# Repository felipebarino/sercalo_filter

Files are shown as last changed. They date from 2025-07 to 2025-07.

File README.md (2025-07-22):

Excelente\! Fico feliz em saber que a correção funcionou bem. O código está muito mais robusto agora.

Com base na sua versão `1.0.0` do `main.c`, reescrevi o `README.md` para refletir com precisão todas as funcionalidades e comandos atuais. Ele está mais claro e agora inclui os comandos de energia que você adicionou.

Aqui está a versão atualizada:

-----

# Controle do Filtro Óptico Sintonizável Sercalo TF1 via ESP32

Este projeto implementa um firmware para o microcontrolador ESP32 para controlar um Filtro Óptico Sintonizável Sercalo TF1. A comunicação com os filtros (Banda C e Banda L) é feita via I2C.

A aplicação principal de exemplo estabelece uma interface de controle via porta serial (UART), permitindo que um usuário ou um programa envie comandos para consultar o estado dos filtros, definir comprimentos de onda específicos ou iniciar varreduras de espectro contínuas.

## Funcionalidades

  * **Driver I2C Dedicado:** Um componente (`sercalo_i2c_driver`) encapsula a comunicação e os comandos do protocolo I2C do filtro Sercalo TF1, de acordo com o manual do fabricante, incluindo cálculo de CRC-8 para garantir a integridade dos dados.
  * **Arquitetura Baseada em FreeRTOS:** A aplicação utiliza o FreeRTOS para gerenciar tarefas de comunicação e controle, permitindo uma operação não bloqueante e facilmente expansível.
  * **Sistema de Comandos Escalável:** A lógica de processamento de comandos utiliza uma tabela de despacho (*dispatch table*), tornando a adição de novos comandos simples e organizada, sem a necessidade de alterar o fluxo principal.
  * **Controle Robusto via Serial:** Comandos para identificar os filtros, definir comprimentos de onda, obter o estado atual e iniciar varreduras foram implementados. O protocolo é similar ao SCPI, facilitando a automação.
  * **Gerenciamento Automático de Energia:** O firmware garante que os filtros sejam ativados (retirados do modo de repouso) automaticamente antes de executar comandos de operação, aumentando a confiabilidade do sistema.

## Hardware Necessário

  * Placa de desenvolvimento ESP32.
  * Filtro Óptico Sintonizável Sercalo TF1 (Banda C e/ou L).
  * Conexões I2C entre o ESP32 e os filtros (SDA, SCL).
      * No projeto, os pinos estão configurados como:
          * **SCL:** GPIO 22
          * **SDA:** GPIO 21
  * Fonte de alimentação para o ESP32 e para os filtros Sercalo.
  * Cabo USB para programação do ESP32 e para monitoramento/controle via terminal serial.

## Estrutura do Projeto

```text
sercalo_filter/
├── main/
│   ├── CMakeLists.txt
│   └── main.c                  # Lógica principal, tasks e handlers de comando
├── components/
│   └── sercalo_i2c_driver/
│       ├── CMakeLists.txt
│       ├── include/
│       │   └── sercalo_i2c.h   # Interface pública do driver
│       └── sercalo_i2c.c       # Implementação do driver I2C
├── CMakeLists.txt              # CMake principal do projeto
├── sdkconfig                   # Configuração do projeto ESP-IDF
└── README.md                   # Este arquivo
```

## Como Compilar e Gravar

1.  **Configure o Ambiente ESP-IDF:** Certifique-se de que o ESP-IDF está instalado e que as variáveis de ambiente foram exportadas (`. export.sh` ou `get_idf`).

2.  **Configure o Projeto:**

      * Defina o target do ESP32: `idf.py set-target esp32`.
      * Ajuste as configurações do projeto, se necessário, com `idf.py menuconfig`.
          * Verifique se as configurações de GPIO para I2C em `main/main.c` correspondem ao seu hardware.

3.  **Compile o Projeto:**

    ```bash
    idf.py build
    ```

4.  **Grave o Firmware no ESP32:**

      * Conecte o ESP32 ao computador.
      * Execute o comando abaixo, substituindo `/dev/ttyUSB0` pela porta serial correta.
        ```bash
        idf.py -p /dev/ttyUSB0 flash monitor
        ```
      * O comando `monitor` abrirá o terminal serial para interagir com o dispositivo.

## Protocolo de Comunicação

Todos os comandos são enviados via UART e devem seguir um formato específico.

1.  **Início do Comando:** Todo comando deve começar com o caractere dois-pontos (`:`).
2.  **Corpo do Comando:** Segue o nome do comando e seus argumentos, separados por `?` ou `:`.
3.  **Fim do Comando:** O comando é finalizado com um caractere de nova linha (`\n` ou `\r`).

**Formato Geral:**

```
:comando[?|:][argumentos]\n
```

### Formato das Respostas

  * **Sucesso:** A resposta começa com `:ACK`, opcionalmente seguida por dados.
    ```
    :ACK
    :ACK:[dados da resposta]
    ```
  * **Erro:** A resposta começa com `:NACK`, seguida por uma mensagem que descreve o erro.
    ```
    :NACK:[mensagem de erro]
    ```

-----

## Referência de Comandos

### `iden`

Recupera as informações de identificação de ambos os filtros (Banda C e Banda L).

  * **Descrição:** Solicita modelo, número de série (S/N) e versão de firmware de cada canal.
  * **Sintaxe:**
    ```
    :iden\n
    ```
  * **Exemplo de Resposta:**
    ```
    :ACK: Canal C: Modelo=TF, S/N=N/A, FW=7.0 | Canal L: Modelo=TF, S/N=N/A, FW=6.0 | 
    ```

### `get-interval`

Obtém o intervalo operacional (comprimentos de onda mínimo e máximo) de um filtro específico.

  * **Sintaxe:**
    ```
    :get-interval?[banda]\n
    ```
  * **Argumentos:**
      * `banda`: O canal do filtro (`C` ou `L`).
  * **Exemplo de Uso:**
      * **Comando:** `:get-interval?C\n`
      * **Resposta:** `:ACK:(1527.608,1565.503)`

### `get-wl`

Obtém o comprimento de onda (`wavelength`) atual de um filtro específico.

  * **Sintaxe:**
    ```
    :get-wl?[banda]\n
    ```
  * **Argumentos:**
      * `banda`: O canal do filtro (`C` ou `L`).
  * **Exemplo de Uso:**
      * **Comando:** `:get-wl?L\n`
      * **Resposta:** `:ACK:1575.500`

### `set-wl`

Define um novo comprimento de onda para um filtro específico.

  * **Descrição:** Sintoniza o canal para um novo comprimento de onda. Se uma varredura (`sweep`) estiver ativa, ela será interrompida.
  * **Sintaxe:**
    ```
    :set-wl:[banda]:[wavelength]\n
    ```
  * **Argumentos:**
      * `banda`: O canal do filtro a ser sintonizado (`C` ou `L`).
      * `wavelength`: O comprimento de onda desejado em nanômetros (nm).
  * **Exemplo de Uso:**
      * **Comando:** `:set-wl:C:1550.5\n`
      * **Resposta:** `:ACK`

### `sweep`

Inicia uma varredura contínua de comprimento de onda para um filtro. ⚙️

  * **Descrição:** Inicia uma tarefa que varre uma faixa de comprimentos de onda em intervalos de tempo definidos. A varredura reinicia automaticamente ao chegar ao fim. Se uma varredura já estiver ativa no canal, ela será substituída.
  * **Sintaxe:**
    ```
    :sweep:[banda]:[min_wl]:[max_wl]:[passo_wl]:[passo_tempo_ms]\n
    ```
  * **Argumentos:**
      * `banda`: O canal do filtro (`C` ou `L`).
      * `min_wl`: Comprimento de onda inicial (nm).
      * `max_wl`: Comprimento de onda final (nm).
      * `passo_wl`: Incremento do comprimento de onda a cada passo (nm).
      * `passo_tempo_ms`: Intervalo de tempo entre cada passo (milissegundos).
  * **Exemplo de Uso:**
      * **Comando:** `:sweep:L:1570:1605:0.5:1000\n`
      * **Resposta:** `:ACK`

### `powerup`

Força a ativação (modo de energia normal) de ambos os filtros.

  * **Descrição:** Garante que ambos os canais estejam prontos para receber comandos de operação.
  * **Sintaxe:**
    ```
    :powerup\n
    ```
  * **Exemplo de Resposta:**
    ```
    :ACK:Canal C: Ligado | Canal L: Ligado | 
    ```

### `get-power`

Verifica o estado de energia atual de ambos os filtros.

  * **Descrição:** Retorna `1` para modo normal (ligado) e `0` para modo de baixo consumo (repouso).
  * **Sintaxe:**
    ```
    :get-power\n
    ```
  * **Exemplo de Resposta:**
    ```
    :ACK:Canal C: 1 | Canal L: 1 | 
    ```

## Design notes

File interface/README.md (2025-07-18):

# Interface de controle do filtro sintonizável

Este programa é um exemplo para controle do filtro sintonizável via interface USB usando PyQt5 para construir a interface do usuário.

### Estrutura do Projeto (interface)

```
interface/
├── widgets/
│   ├── __init__.py
│   ├── base_widget.py      # Template para o widget de comando
│   ├── get_iden_widget.py  # Obter dados dos dispositivos
│   ├── get_wl_widget.py    # Obter comprimento de onda
│   ├── set_wl_widget.py    # Controle do comprimento de onda
│   └── sweep_widget.py     # Controle da varredura
├── main.py                 # Ponto de entrada
├── main_window.py          # Tela principal
├── communication.py        # Módulo de comunicações
└── README.md               # Este arquivo de documentação
```

## Referência de Comandos da UART

O dispositivo se comunica via UART usando o seguinte protocolo:

  - **Formato do Comando:** `:comando[?|:][argumentos]\n`
  - **Resposta de Sucesso:** `:ACK:[dados]\n` ou `:ACK\n`
  - **Resposta de Falha:** `:NACK:[mensagem_erro]\n`

| Comando | Descrição | Exemplo de Uso | Resposta de Sucesso Esperada |
| :--- | :--- | :--- | :--- |
| `iden?` | Obtém a identificação (Modelo, S/N, FW) de ambos os filtros. | `:iden?\n` | `:ACK: Canal C: ... \| Canal L: ... \|` |
| `get-interval?[B]`| Obtém o intervalo de WL (min, max) da banda `[B]` (`C` ou `L`). | `:get-interval?C\n` | `:ACK: (1527.608,1565.503)` |
| `get-wl?[B]` | Obtém o WL atual da banda `[B]`. | `:get-wl?L\n` | `:ACK: 1575.500` |
| `set-wl:[B]:[W]` | Define o WL `[W]` para a banda `[B]`. Para a varredura se ativa. | `:set-wl:C:1550.5\n` | `:ACK` |
| `sweep:[B]:[..]`| Inicia uma varredura. Args: `B:min:max:passo_wl:passo_t`. | `:sweep:L:1570:1605:0.5:1000\n` | `:ACK` |

## Requisitos

  - Python 3.7+
  - Bibliotecas: `PyQt5` e `pyserial`

## Instalação

1.  **Navegue até a pasta da interface:**
    ```bash
    cd sercalo_filter/interface
    ```
2.  **Instale as dependências:**
    ```bash
    pip install PyQt5 pyserial
    ```

## Como Usar

1.  **Execute a Aplicação:**
    ```bash
    python main.py
    ```
2.  **Conecte ao Dispositivo:**
      - Selecione a porta serial correta na lista suspensa (onde o seu ESP32 está conectado).
      - Clique em "Atualizar" se a porta não aparecer.
      - Clique em "Conectar". O botão mudará para "Desconectar".
3.  **Opere os Filtros:**
      - Use os diferentes "widgets" na interface para enviar comandos.
      - Cada widget possui um campo de status (`Pronto.`, `OK`, ou `Erro: ...`) que exibe o resultado do último comando enviado por ele.

## Estrutura do Projeto e Extensibilidade

A interface utiliza uma arquitetura de **widgets modulares**. Para adicionar um controle para um novo comando:

1.  **Crie um novo arquivo** em `widgets/`, por exemplo, `widgets/meu_novo_widget.py`.
2.  **Crie uma classe** que herde de `BaseCommandWidget`.
3.  **Desenvolva a interface** específica para o seu comando dentro desta classe.
4.  **Emita o sinal** `send_command_requested` com a string do comando formatada.
5.  **Importe e instancie** seu novo widget no `main_window.py`.
    O sistema de comunicação e a janela principal cuidarão do resto.

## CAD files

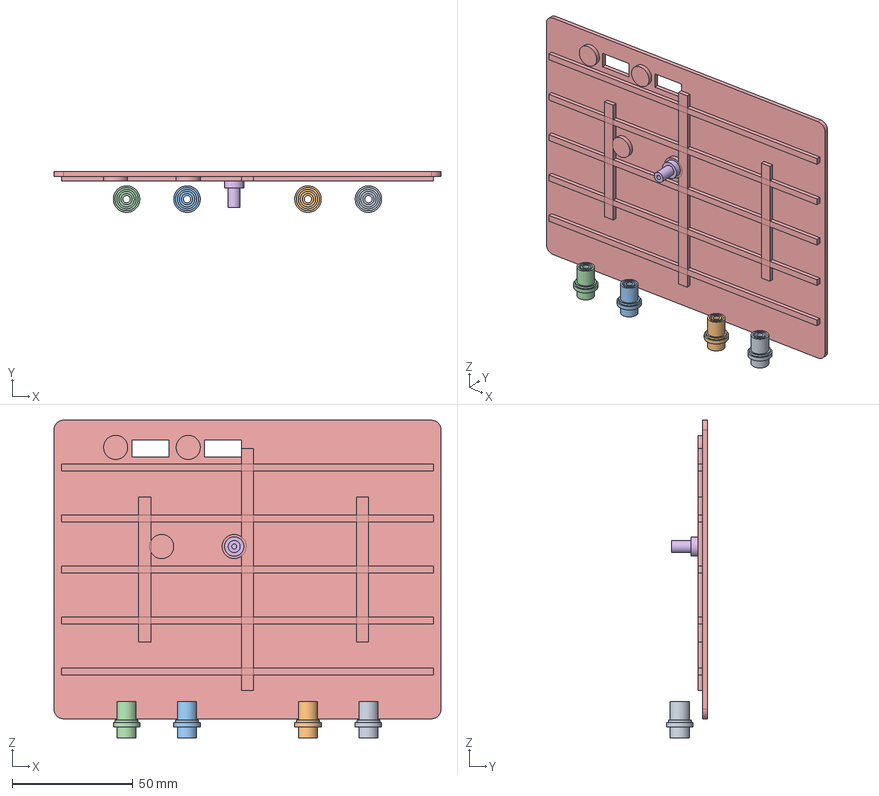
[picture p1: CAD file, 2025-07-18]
_hardware/Mecânico/Montagem.FCStd
160.0 x 16.9 x 131.3 mm
I_optico_Cin
I_optico_Cout
I_optico_Lin
I_optico_Lout
prateleira
Corpo

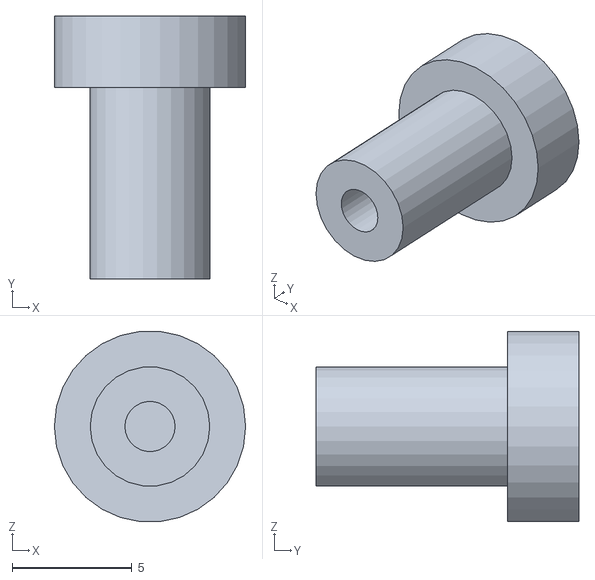
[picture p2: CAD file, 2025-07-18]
_hardware/Mecânico/Montagem-suporte_placa.stl
8.00 x 11.0 x 7.96

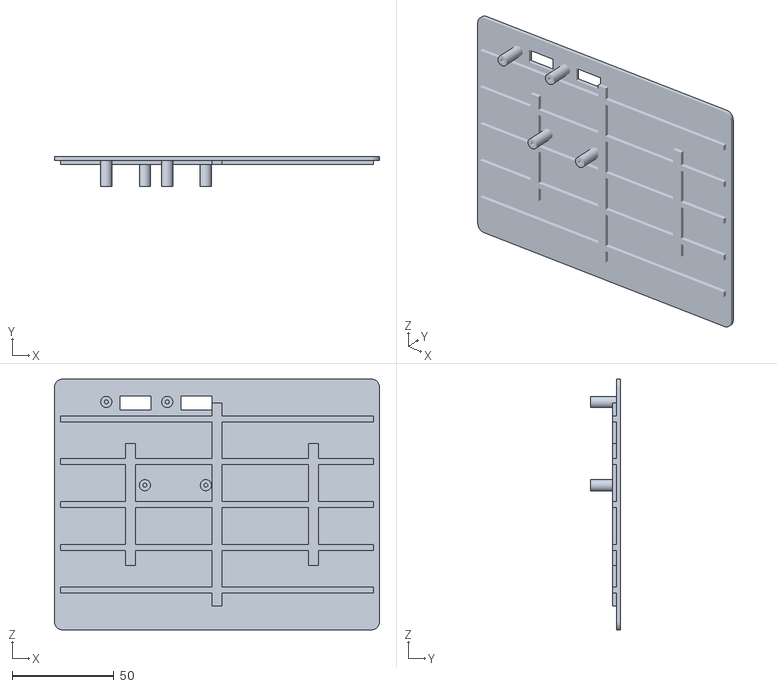
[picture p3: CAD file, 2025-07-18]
_hardware/Mecânico/Montagem-prateleira.stl
160.0 x 14.8 x 123.5

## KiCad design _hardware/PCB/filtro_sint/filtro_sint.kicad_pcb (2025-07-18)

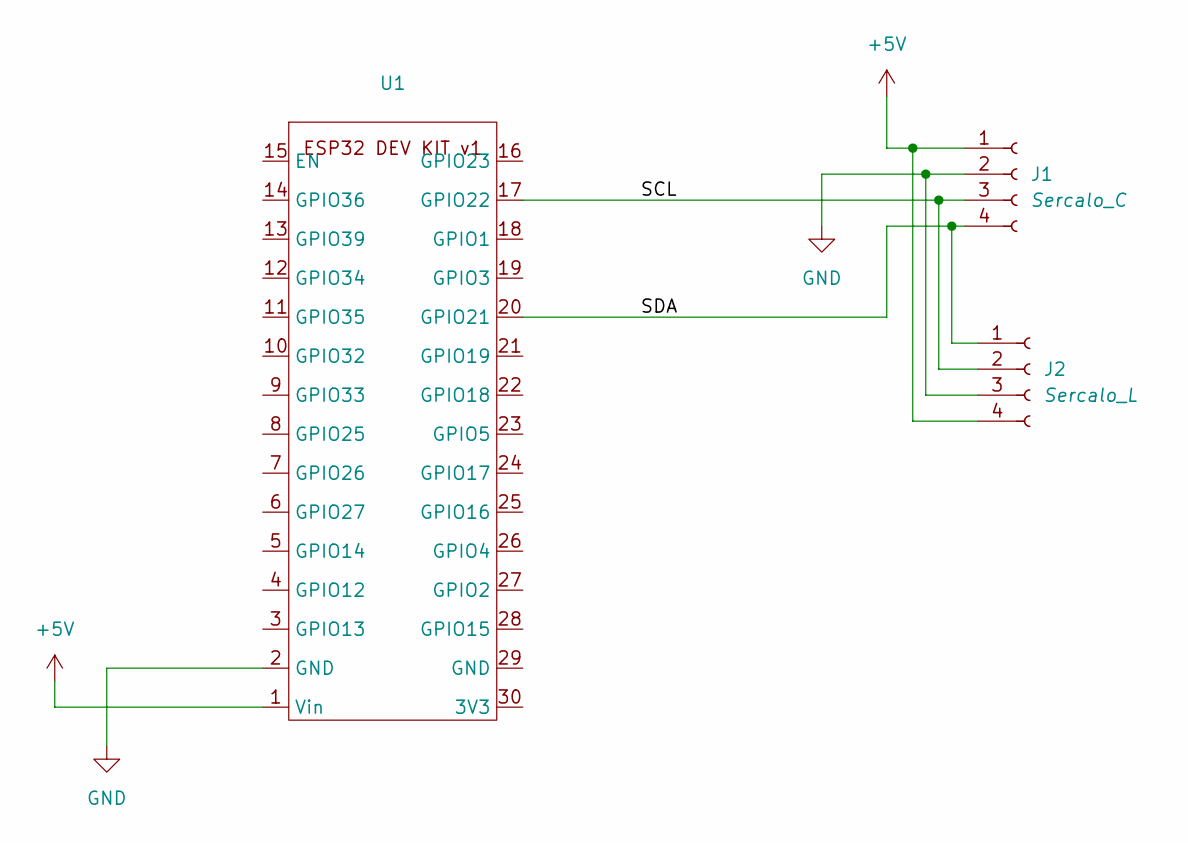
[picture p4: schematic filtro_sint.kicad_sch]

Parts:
J1: Sercalo_C; Molex_KK-254_AE-6410-04A_1x04_P2.54mm_Vertical
J2: Sercalo_L; Molex_KK-254_AE-6410-04A_1x04_P2.54mm_Vertical
U1: esp32_devkitv1_doit

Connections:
+5V: J1.1, J2.4, U1.1 (Vin)
/SCL: J1.3, J2.2, U1.17 (GPIO22)
/SDA: J1.4, J2.1, U1.20 (GPIO21)
GND: J1.2, J2.3, U1.2 (GND)

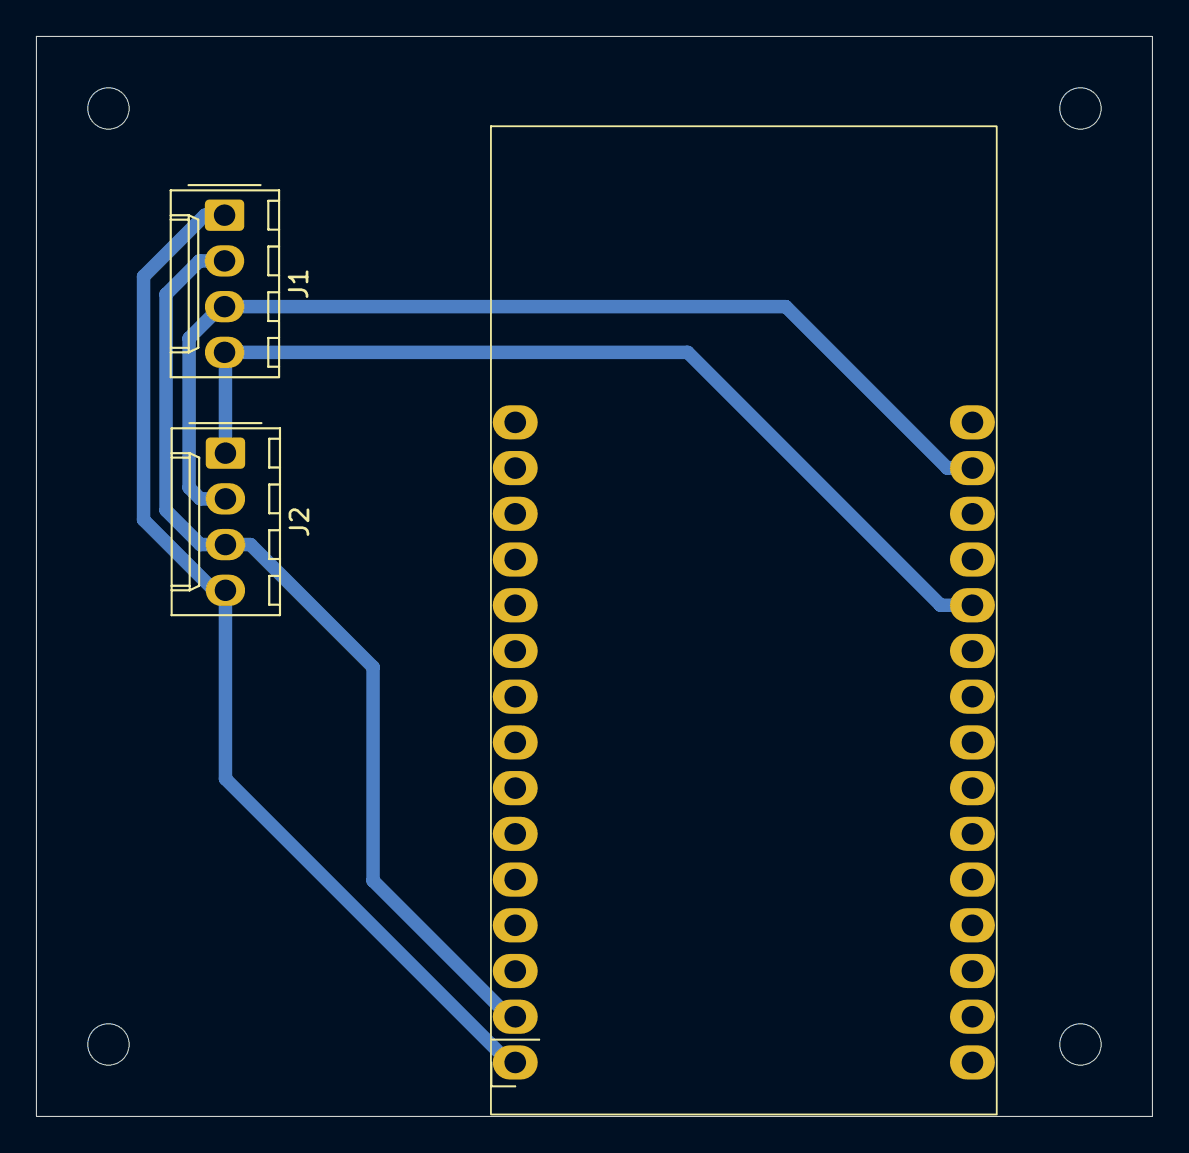
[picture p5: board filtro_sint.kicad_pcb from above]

Board: 2 copper layers, 62.0 x 60.0 mm, 3 parts (0 on the bottom side), 4 nets.

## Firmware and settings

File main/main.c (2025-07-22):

/**************************************************************************************************
* Arquivo:      sercalo_i2c.c
* Autor:        Felipe Oliveira Barino
* Data:         2024-07-22
* Versão:       1.0.0
*
* Descrição:    Implementação das funções de driver para comunicação I2C com o
* Filtro Óptico Sintonizável Sercalo TF1.
*
* Plataforma:   ESP32
* Compilador:   xtensa-esp32-elf-gcc (baseado no ESP-IDF do projeto original)
*
* Dependências: ESP-IDF
*
* Notas:        Adaptado do driver do Switch Óptico para o Filtro Óptico Sintonizável TF1.
*
* Histórico de Modificações:
* [Data] - [Autor] - [Versão] - [Descrição da Modificação]
* 2024-07-17 - Barino - 0.1.0 - Versão inicial (sem testes)
* 2024-07-18 - Barino - 0.1.1 - Documentação e comentários
* 2024-07-22 - Barino - 1.0.0 - Mínima versão funcional
* 
**************************************************************************************************/
#include <stdio.h>
#include <string.h>
#include <stdlib.h>
#include <ctype.h>
#include "freertos/FreeRTOS.h"
#include "freertos/task.h"
#include "freertos/semphr.h"
#include "esp_log.h"
#include "driver/i2c.h"
#include "sercalo_i2c.h" // Inclui o driver de baixo nível do dispositivo Sercalo

// --- Configurações do Barramento I2C ---
#define I2C_MASTER_SCL_IO           22          // Pino GPIO para o clock I2C (SCL)
#define I2C_MASTER_SDA_IO           21          // Pino GPIO para os dados I2C (SDA)
#define I2C_MASTER_NUM              I2C_NUM_0   // Porta I2C a ser usada (0 ou 1)
#define I2C_MASTER_FREQ_HZ          100000      // Frequência do clock I2C (100 KHz)

// --- Endereços I2C dos Dispositivos ---
#define C_BAND_FILTER_ADDR          0x3F        // Endereço I2C do filtro da Banda C
#define L_BAND_FILTER_ADDR          0x7F        // Endereço I2C do filtro da Banda L

// --- Definições de Buffers ---
#define CMD_BUFFER_SIZE             128         // Tamanho máximo do buffer para comandos recebidos via UART.
#define RESPONSE_DATA_BUFFER_SIZE   256         // Tamanho máximo do buffer para respostas de comandos.

// --- Variáveis Globais ---
static const char *TAG = "SERCALO_FILTER_APP";

/**
 * @struct filter_channel_t
 * @brief  Agrupa todos os dados e estados de um único canal de filtro.
 */
typedef struct {
    sercalo_dev_t device_handle;    /*!< Handle para o driver de baixo nível do dispositivo Sercalo. */
    char name[2];                   /*!< Nome do canal para identificação ("C" ou "L"). */
    TaskHandle_t sweep_task_handle; /*!< Handle para a task de sweep, se ativa. NULL caso contrário. */
} filter_channel_t;

// Array global contendo os dois canais de filtro.
static filter_channel_t g_filter_channels[2]; // Posição 0: Banda C, Posição 1: Banda L

// --- Primitivas de Sincronização e Comunicação Inter-Task ---
static char g_received_cmd_buffer[CMD_BUFFER_SIZE];                             /*!< Buffer global para armazenar o último comando recebido da UART. */
static SemaphoreHandle_t g_command_mutex;                                       /*!< Mutex para garantir acesso exclusivo aos periféricos I2C, evitando colisões. */
static TaskHandle_t g_command_processor_task_handle = NULL;                     /*!< Handle da task processadora de comandos, para notificação. */
static portMUX_TYPE g_command_buffer_spinlock = portMUX_INITIALIZER_UNLOCKED;   /*!< Spinlock de baixo nível (mux) para proteger o acesso ao buffer global g_received_cmd_buffer. */

// --- Estrutura para Tabela de Despacho de Comandos (Command Dispatcher) ---

/**
 * @brief  Define a assinatura padrão para todas as funções que manipulam um comando. 
 */
typedef esp_err_t (*command_handler_t)(char *args, char *response_buf, size_t response_buf_len);

/**
 * @struct command_entry_t
 * @brief  Associa o nome de um comando (string) a uma função (ponteiro de função) que o implementa.
 */
typedef struct {
    const char *command_name;       /*!< A string exata que aciona o comando. */
    command_handler_t handler;      /*!< Ponteiro para a função que executa a lógica do comando. */
} command_entry_t;

// Protótipos dos Handlers de Comando
esp_err_t handle_get_iden(char *args, char *response_buf, size_t response_buf_len);
esp_err_t handle_get_interval(char *args, char *response_buf, size_t response_buf_len);
esp_err_t handle_get_wl(char *args, char *response_buf, size_t response_buf_len);
esp_err_t handle_set_wl(char *args, char *response_buf, size_t response_buf_len);
esp_err_t handle_sweep(char *args, char *response_buf, size_t response_buf_len);
esp_err_t handle_powerup(char *args, char *response_buf, size_t response_buf_len);
esp_err_t handle_get_power(char *args, char *response_buf, size_t response_buf_len);

// Tabela de Comandos: adicionar novas linhas com comando e sua função.
static const command_entry_t command_table[] = {
    {"iden", handle_get_iden},
    {"get-interval", handle_get_interval},
    {"get-wl", handle_get_wl},
    {"set-wl", handle_set_wl},
    {"sweep", handle_sweep},
    {"powerup", handle_powerup},
    {"get-power", handle_get_power},
};
// Calcula o número de comandos na tabela em tempo de compilação.
static const int num_commands = sizeof(command_table) / sizeof(command_entry_t);


// --- Funções Auxiliares ---

/**
 * @brief Seleciona o canal de filtro (Banda C ou L) com base em um caractere.
 * @param band_char Caractere que representa a banda ('C' ou 'L', insensível a maiúsculas/minúsculas).
 * @return Ponteiro para a estrutura `filter_channel_t` correspondente, ou NULL se a banda for inválida.
 */
static filter_channel_t* select_filter_channel(const char band_char) {
    if (toupper(band_char) == 'C') {
        return &g_filter_channels[0];
    } else if (toupper(band_char) == 'L') {
        return &g_filter_channels[1];
    }
    return NULL;
}

/**
 * @brief Para e deleta uma tarefa de sweep, se ela estiver ativa para um determinado canal.
 * @param channel Ponteiro para o canal de filtro cuja tarefa de sweep deve ser parada.
 */
static void stop_sweep_if_active(filter_channel_t *channel) {
    if (channel->sweep_task_handle != NULL) {
        ESP_LOGI(TAG, "Parando task de sweep para o canal %s", channel->name);
        vTaskDelete(channel->sweep_task_handle);
        channel->sweep_task_handle = NULL;
    }
}

/**
 * @brief Garante que um canal de filtro esteja no modo de energia normal.
 *
 * Esta função de ajuda verifica o modo de energia atual do canal. Se estiver
 * em baixo consumo (idle), ela envia o comando para ativar o modo normal
 * e aguarda um tempo para a estabilização do dispositivo.
 *
 * @param channel Ponteiro para o canal de filtro a ser verificado e ativado.
 * @return ESP_OK se o canal está ou foi colocado com sucesso em modo normal.
 * @return ESP_FAIL se a comunicação ou ativação falhar.
 */
static esp_err_t ensure_power_on(filter_channel_t *channel) {
    sercalo_power_mode_t current_mode;
    esp_err_t ret;

    // 1. Verifica o estado de energia atual.
    ret = sercalo_get_set_power_mode(&channel->device_handle, NULL, &current_mode);
    if (ret != ESP_OK) {
        ESP_LOGE(TAG, "Falha ao obter o modo de energia para o canal %s", channel->name);
        return ESP_FAIL;
    }

    // 2. Se estiver em modo de baixo consumo, ativa o modo normal.
    if (current_mode == SERCALO_POWER_LOW) {
        ESP_LOGI(TAG, "Canal %s está em modo de repouso. Ativando...", channel->name);
        sercalo_power_mode_t power_on = SERCALO_POWER_NORMAL;
        ret = sercalo_get_set_power_mode(&channel->device_handle, &power_on, NULL);
        if (ret != ESP_OK) {
            ESP_LOGE(TAG, "Falha ao ativar o modo de energia para o canal %s", channel->name);
            return ESP_FAIL;
        }
        // Adiciona um delay para garantir que o dispositivo tenha tempo para estabilizar.
        vTaskDelay(pdMS_TO_TICKS(100)); 
    }

    return ESP_OK;
}


// --- Tasks ---

/**
 * @struct sweep_params_t
 * @brief  Estrutura para passar todos os parâmetros necessários para a `wavelength_sweep_task`.
 */
typedef struct {
    filter_channel_t *channel;
    float min_wl;
    float max_wl;
    float wl_interval;
    int time_interval_ms;
} sweep_params_t;

/**
 * @brief Task que realiza uma varredura contínua de comprimento de onda.
 *
 * Esta tarefa entra em um loop infinito, varrendo de um `min_wl` a um `max_wl`
 * com um passo e atraso definidos. A tarefa é criada pelo comando 'sweep' e
 * destruída pelos comandos 'set-wl' ou por um novo comando 'sweep' no mesmo canal.
 * @param pvParameters Ponteiro para uma estrutura `sweep_params_t` contendo os parâmetros da varredura.
 */
void wavelength_sweep_task(void *pvParameters) {
    // Copia os parâmetros para a stack da task para liberar a memória do chamador.
    sweep_params_t params = *(sweep_params_t *)pvParameters;
    filter_channel_t *channel = params.channel;

    char task_tag[32];
    snprintf(task_tag, sizeof(task_tag), "SWEEP_%s", channel->name);

    ESP_LOGI(task_tag, "Iniciando varredura: min=%.3f, max=%.3f, step=%.3f, delay=%dms",
             params.min_wl, params.max_wl, params.wl_interval, params.time_interval_ms);

    while (1) {
        for (float current_wl = params.min_wl; current_wl <= params.max_wl; current_wl += params.wl_interval) {
            ESP_LOGD(task_tag, "Definindo wl: %.3f nm", current_wl);
            float target_wl = current_wl;

            // Usa o mutex para garantir que esta operação não conflite com outros comandos I2C.
            if (xSemaphoreTake(g_command_mutex, portMAX_DELAY) == pdTRUE) {
                sercalo_get_set_wavelength(&channel->device_handle, &target_wl, NULL);
                xSemaphoreGive(g_command_mutex);
            }
            vTaskDelay(pdMS_TO_TICKS(params.time_interval_ms));
        }
        ESP_LOGI(task_tag, "Varredura concluída. Reiniciando...");
    }
}

// --- Implementações dos Handlers de Comando ---

/**
 * @brief Handler para o comando `iden?`.
 *
 * Obtém os dados de identificação (Modelo, S/N, FW) de ambos os canais (C e L)
 * e os concatena no buffer de resposta.
 *
 * @param args Não utilizado neste comando.
 * @param response_buf Buffer para onde a string de resposta formatada será escrita.
 * @param response_buf_len Tamanho total do buffer de resposta.
 *
 * @return ESP_OK Sempre retorna sucesso, mesmo que a leitura de um dos canais falhe
 * (nesse caso, uma mensagem de falha é incluída na própria resposta).
 *
 * @note **Respostas pela Serial:**
 * - **Sucesso (:ACK):** `:ACK: Canal C: Modelo=..., S/N=..., FW=... | Canal L: Modelo=..., S/N=..., FW=... |\n`
 * - **Falha (:NACK):** Este comando não gera NACK. Falhas de leitura são reportadas dentro da string de ACK.
 */
esp_err_t handle_get_iden(char *args, char *response_buf, size_t response_buf_len) {
    char temp_buf[RESPONSE_DATA_BUFFER_SIZE / 2];
    response_buf[0] = '\0'; // Assegura que o buffer de resposta está vazio.

    for (int i = 0; i < 2; i++) { // Itera sobre os dois canais
        filter_channel_t *channel = &g_filter_channels[i];
        sercalo_id_t id_data;
        esp_err_t ret;

        if (xSemaphoreTake(g_command_mutex, portMAX_DELAY) == pdTRUE) {
            ret = sercalo_get_id(&channel->device_handle, &id_data);
            xSemaphoreGive(g_command_mutex);

            if (ret == ESP_OK) {
                snprintf(temp_buf, sizeof(temp_buf), "Canal %s: Modelo=%s, S/N=%s, FW=%s | ",
                         channel->name, id_data.model, id_data.serial_number, id_data.fw_version);
            } else {
                snprintf(temp_buf, sizeof(temp_buf), "Canal %s: Falha ao ler ID | ", channel->name);
            }
            // Concatena a resposta do canal no buffer final, com segurança.
            strncat(response_buf, temp_buf, response_buf_len - strlen(response_buf) - 1);
        }
    }
    return ESP_OK;
}

/**
 * @brief Handler para o comando `get-interval`.
 *
 * Obtém o intervalo de comprimento de onda operacional (mínimo e máximo)
 * para um canal especificado.
 *
 * @param args Ponteiro para a string de argumentos. Espera um caractere de banda ('C' ou 'L'). Ex: "C"
 * @param response_buf Buffer para onde a resposta `(min,max)` será escrita.
 * @param response_buf_len Tamanho do buffer de resposta.
 *
 * @return ESP_OK se a leitura do intervalo for bem-sucedida.
 * @return ESP_ERR_INVALID_ARG se a banda especificada for inválida.
 * @return ESP_FAIL se a comunicação I2C com o dispositivo falhar.
 *
 * @note **Respostas pela Serial:**
 * - **Sucesso (:ACK):** `:ACK: (1527.608,1565.503)\n`
 * - **Falha (:NACK):** `:NACK: ESP_ERR_INVALID_ARG\n` ou `:NACK: ESP_FAIL\n`
 */
esp_err_t handle_get_interval(char *args, char *response_buf, size_t response_buf_len) {
    char *band_char_str = strtok_r(args, "?", &args);
    if (!band_char_str) return ESP_ERR_INVALID_ARG;
    
    filter_channel_t *channel = select_filter_channel(band_char_str[0]);
    if (!channel) return ESP_ERR_INVALID_ARG;

    float min_lambda, max_lambda;
    esp_err_t ret_min, ret_max;

    if (xSemaphoreTake(g_command_mutex, portMAX_DELAY) == pdTRUE) {
        ret_min = sercalo_get_min_wavelength(&channel->device_handle, &min_lambda);
        ret_max = sercalo_get_max_wavelength(&channel->device_handle, &max_lambda);
        xSemaphoreGive(g_command_mutex);
    } else { return ESP_FAIL; }

    if (ret_min == ESP_OK && ret_max == ESP_OK) {
        snprintf(response_buf, response_buf_len, "(%.3f,%.3f)", min_lambda, max_lambda);
        return ESP_OK;
    }
    return ESP_FAIL;
}

/**
 * @brief Handler para o comando `get-wl`.
 *
 * Obtém o comprimento de onda atual em que um canal específico está sintonizado.
 *
 * @param args Ponteiro para a string de argumentos. Espera um caractere de banda ('C' ou 'L'). Ex: "L"
 * @param response_buf Buffer para onde o valor do comprimento de onda será escrito.
 * @param response_buf_len Tamanho do buffer de resposta.
 *
 * @return ESP_OK se a leitura for bem-sucedida.
 * @return ESP_ERR_INVALID_ARG se a banda especificada for inválida.
 * @return ESP_FAIL se a comunicação I2C falhar.
 *
 * @note **Respostas pela Serial:**
 * - **Sucesso (:ACK):** `:ACK: 1550.123\n`
 * - **Falha (:NACK):** `:NACK: ESP_ERR_INVALID_ARG\n` ou `:NACK: ESP_FAIL\n`
 */
esp_err_t handle_get_wl(char *args, char *response_buf, size_t response_buf_len) {
    char *band_char_str = strtok_r(args, "?", &args);
    if (!band_char_str) return ESP_ERR_INVALID_ARG;

    filter_channel_t *channel = select_filter_channel(band_char_str[0]);
    if (!channel) return ESP_ERR_INVALID_ARG;

    float current_lambda;
    esp_err_t ret;

    if (xSemaphoreTake(g_command_mutex, portMAX_DELAY) == pdTRUE) {
        ensure_power_on(channel); // Garante que o canal está no modo normal antes de ler o comprimento de onda.
        xSemaphoreGive(g_command_mutex);
    } else { return ESP_FAIL; }
    
    if (xSemaphoreTake(g_command_mutex, portMAX_DELAY) == pdTRUE) {
        ret = sercalo_get_set_wavelength(&channel->device_handle, NULL, &current_lambda);
        xSemaphoreGive(g_command_mutex);
    } else { return ESP_FAIL; }

    if (ret == ESP_OK) {
        snprintf(response_buf, response_buf_len, "%.3f", current_lambda);
        return ESP_OK;
    }
    return ESP_FAIL;
}

/**
 * @brief Handler para o comando `set-wl`.
 *
 * Define um novo comprimento de onda para um canal específico. Se uma tarefa de
 * varredura (`sweep`) estiver ativa no canal, ela será interrompida.
 *
 * @param args Ponteiro para os argumentos. Formato esperado: "[banda]:[wavelength]". Ex: "C:1550.5"
 * @param response_buf Não utilizado neste comando (a resposta de sucesso não contém dados).
 * @param response_buf_len Não utilizado.
 *
 * @return ESP_OK se o comprimento de onda for definido com sucesso.
 * @return ESP_ERR_INVALID_ARG se os argumentos forem malformados, a banda for inválida ou o valor de wl for inválido.
 * @return ESP_FAIL se a comunicação I2C falhar.
 *
 * @note **Respostas pela Serial:**
 * - **Sucesso (:ACK):** `:ACK\n`
 * - **Falha (:NACK):** `:NACK: ESP_ERR_INVALID_ARG\n` ou `:NACK: ESP_FAIL\n`
 */
esp_err_t handle_set_wl(char *args, char *response_buf, size_t response_buf_len) {
    char *band_str = strtok_r(args, ":", &args);
    char *wl_str = strtok_r(NULL, ":", &args);

    if (!band_str || !wl_str) return ESP_ERR_INVALID_ARG;

    filter_channel_t *channel = select_filter_channel(band_str[0]);
    if (!channel) return ESP_ERR_INVALID_ARG;

    if (xSemaphoreTake(g_command_mutex, portMAX_DELAY) == pdTRUE) {
        ensure_power_on(channel); // Garante que o canal está no modo normal antes de ler o comprimento de onda.
        xSemaphoreGive(g_command_mutex);
    } else { return ESP_FAIL; }
    
    float target_wl = atof(wl_str);
    if (target_wl <= 0) return ESP_ERR_INVALID_ARG;

    stop_sweep_if_active(channel);
    
    esp_err_t ret;
    if (xSemaphoreTake(g_command_mutex, portMAX_DELAY) == pdTRUE) {
        ret = sercalo_get_set_wavelength(&channel->device_handle, &target_wl, NULL);
        xSemaphoreGive(g_command_mutex);
    } else { return ESP_FAIL; }
    
    return ret;
}

/**
 * @brief Handler para o comando `sweep`.
 *
 * Inicia uma tarefa de varredura contínua de comprimento de onda para um canal.
 * Se uma varredura já estiver ativa, ela é parada e substituída pela nova.
 *
 * @param args Ponteiro para os argumentos. Formato: "[banda]:[min_wl]:[max_wl]:[passo_wl]:[passo_tempo_ms]".
 * Ex: "L:1570:1605:0.5:1000"
 * @param response_buf Não utilizado (a resposta de sucesso não contém dados).
 * @param response_buf_len Não utilizado.
 *
 * @return ESP_OK se a tarefa de sweep for criada com sucesso.
 * @return ESP_ERR_INVALID_ARG se os argumentos forem malformados ou inválidos.
 * @return ESP_FAIL se a criação da task falhar (por exemplo, por falta de memória).
 *
 * @note **Respostas pela Serial:**
 * - **Sucesso (:ACK):** `:ACK\n`
 * - **Falha (:NACK):** `:NACK: ESP_ERR_INVALID_ARG\n` ou `:NACK: ESP_FAIL\n`
 */
esp_err_t handle_sweep(char *args, char *response_buf, size_t response_buf_len) {
    // Extrai todos os 5 parâmetros do comando.
    char *band_str = strtok_r(args, ":", &args);
    char *min_wl_str = strtok_r(NULL, ":", &args);
    char *max_wl_str = strtok_r(NULL, ":", &args);
    char *wl_interval_str = strtok_r(NULL, ":", &args);
    char *time_interval_str = strtok_r(NULL, ":", &args);

    if (!band_str || !min_wl_str || !max_wl_str || !wl_interval_str || !time_interval_str) {
        return ESP_ERR_INVALID_ARG;
    }

    filter_channel_t *channel = select_filter_channel(band_str[0]);
    if (!channel) return ESP_ERR_INVALID_ARG;

    sweep_params_t params = {
        .channel = channel,
        .min_wl = atof(min_wl_str),
        .max_wl = atof(max_wl_str),
        .wl_interval = atof(wl_interval_str),
        .time_interval_ms = atoi(time_interval_str)
    };
    
    if (params.min_wl <= 0 || params.max_wl <= params.min_wl || params.wl_interval <= 0 || params.time_interval_ms <= 0) {
        return ESP_ERR_INVALID_ARG;
    }

    stop_sweep_if_active(channel);

    char task_name[16];
    snprintf(task_name, sizeof(task_name), "sweep_%s_task", channel->name);

    // Cria a task de varredura.
    if (xTaskCreate(wavelength_sweep_task, task_name, 4096, &params, 5, &channel->sweep_task_handle) != pdPASS) {
        channel->sweep_task_handle = NULL;
        return ESP_FAIL;
    }
    
    return ESP_OK;
}
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
void app_main(void) {
    ESP_LOGI(TAG, "Iniciando aplicação de controle de Filtros Sercalo.");

    ESP_ERROR_CHECK(i2c_master_init());
    ESP_LOGI(TAG, "Driver I2C inicializado com sucesso.");

    // Inicializa o Canal da Banda C.
    strncpy(g_filter_channels[0].name, "C", 2);
    g_filter_channels[0].sweep_task_handle = NULL;
    ESP_ERROR_CHECK(sercalo_i2c_init_device(&g_filter_channels[0].device_handle, I2C_MASTER_NUM, C_BAND_FILTER_ADDR));
    ESP_LOGI(TAG, "Filtro Banda C inicializado no endereço 0x%02X.", C_BAND_FILTER_ADDR);

    // Inicializa o Canal da Banda L.
    strncpy(g_filter_channels[1].name, "L", 2);
    g_filter_channels[1].sweep_task_handle = NULL;
    ESP_ERROR_CHECK(sercalo_i2c_init_device(&g_filter_channels[1].device_handle, I2C_MASTER_NUM, L_BAND_FILTER_ADDR));
    ESP_LOGI(TAG, "Filtro Banda L inicializado no endereço 0x%02X.", L_BAND_FILTER_ADDR);

    // Cria o mutex para proteger o acesso ao I2C.
    g_command_mutex = xSemaphoreCreateMutex();

    // Cria as tasks principais da aplicação.
    xTaskCreate(command_processor_task, "CmdProcessorTask", 4096, NULL, 5, NULL); // Prioridade 5
    xTaskCreate(uart_command_monitor_task, "UartMonitorTask", 4096, NULL, 6, NULL); // Prioridade maior para não perder comandos

    ESP_LOGI(TAG, "Sistema pronto. Aguardando comandos via UART...");
}

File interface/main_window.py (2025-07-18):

# main_window.py

import serial
import sys
from PyQt5.QtWidgets import (QApplication, QMainWindow, QWidget, QVBoxLayout,
                             QComboBox, QPushButton, QHBoxLayout, QLabel, QMessageBox)
from PyQt5.QtCore import QThread, pyqtSlot
from communication import SerialCommunicator, serial_ports
from widgets.get_wl_widget import GetWlWidget
from widgets.set_wl_widget import SetWlWidget
from widgets.get_iden_widget import GetIdenWidget
from widgets.sweep_widget import SweepWidget

class MainWindow(QMainWindow):
    def __init__(self, parent=None):
        super().__init__(parent)
        self.setWindowTitle("Controlador de Filtro Sercalo")
        self.setGeometry(100, 100, 500, 400)

        # Thread de comunicação
        self.comm_thread = None
        self.communicator = None

        # --- Layout Principal ---
        self.central_widget = QWidget()
        self.main_layout = QVBoxLayout()
        self.central_widget.setLayout(self.main_layout)
        self.setCentralWidget(self.central_widget)

        # --- Seção de Conexão ---
        connection_layout = QHBoxLayout()
        self.port_selector = QComboBox()
        self.refresh_button = QPushButton("Atualizar")
        self.connect_button = QPushButton("Conectar")
        connection_layout.addWidget(QLabel("Porta Serial:"))
        connection_layout.addWidget(self.port_selector)
        connection_layout.addWidget(self.refresh_button)
        connection_layout.addWidget(self.connect_button)
        self.main_layout.addLayout(connection_layout)

        # --- Widgets de Comando (aqui está a escalabilidade!) ---
        self.command_widgets = []
        
        # Crie instâncias dos seus widgets
        self.get_wl_widget = GetWlWidget()
        self.set_wl_widget = SetWlWidget()
        self.get_iden_widget = GetIdenWidget()
        self.sweep_widget = SweepWidget()
        
        # Adicione-os ao layout e a uma lista de gerenciamento
        self.main_layout.addWidget(self.get_wl_widget)
        self.command_widgets.append(self.get_wl_widget)
        
        self.main_layout.addWidget(self.set_wl_widget)
        self.command_widgets.append(self.set_wl_widget)

        self.main_layout.addWidget(self.get_iden_widget)
        self.command_widgets.append(self.get_iden_widget)

        self.main_layout.addWidget(self.sweep_widget)
        self.command_widgets.append(self.sweep_widget)
        
        # Adicione aqui outros widgets que você criar
        
        self.main_layout.addStretch() # Empurra tudo para cima

        # --- Conectar Sinais e Slots ---
        self.refresh_button.clicked.connect(self.populate_ports)
        self.connect_button.clicked.connect(self.toggle_connection)
        
        # Conecta o sinal de cada widget ao comunicador
        for widget in self.command_widgets:
            widget.send_command_requested.connect(self.send_command_from_widget)

        self.populate_ports()

    def populate_ports(self):
        """Busca e exibe as portas seriais disponíveis."""
        self.port_selector.clear()
        port_names = serial_ports()
        for port in port_names:
            self.port_selector.addItem(port)

    def toggle_connection(self):
        """Conecta ou desconecta do dispositivo serial."""
        if self.communicator is None: # Se não está conectado
            port_name = self.port_selector.currentText()
            if not port_name:
                QMessageBox.warning(self, "Sem Porta", "Nenhuma porta serial selecionada.")
                return

            self.comm_thread = QThread()
            self.communicator = SerialCommunicator(port_name)
            self.communicator.moveToThread(self.comm_thread)

            # Conecta os sinais do comunicador à GUI
            self.comm_thread.started.connect(self.communicator.connect)
            self.communicator.response_received.connect(self.handle_response)
            self.communicator.error_received.connect(self.handle_error)
            self.communicator.port_closed.connect(self.on_disconnected)

            self.comm_thread.start()
            self.connect_button.setText("Desconectar")
            self.refresh_button.setEnabled(False)
            self.port_selector.setEnabled(False)

        else: # Se está conectado
            self.communicator.disconnect()

    def on_disconnected(self):
        """Chamado quando a porta é fechada."""
        if self.comm_thread:
            self.comm_thread.quit()
            self.comm_thread.wait()
        self.comm_thread = None
        self.communicator = None
        
        self.connect_button.setText("Conectar")
        self.refresh_button.setEnabled(True)
        self.port_selector.setEnabled(True)

    @pyqtSlot(str)
    def send_command_from_widget(self, command):
        """Envia um comando vindo de qualquer widget."""
        if self.communicator:
            self.communicator.send_command(command)
        else:
            QMessageBox.warning(self, "Desconectado", "Conecte-se a uma porta serial primeiro.")

    def handle_response(self, response):
        """Distribui a resposta para o widget correto (se necessário)."""
        # Lógica futura: se a resposta precisar atualizar um widget específico,
        # você pode implementar um sistema de roteamento aqui.
        # Por simplicidade, atualizamos todos por enquanto.
        for widget in self.command_widgets:
            widget.update_status(response)

    def handle_error(self, error_message):
        """Distribui a mensagem de erro."""
        for widget in self.command_widgets:
            widget.update_status(error_message, is_error=True)

    def closeEvent(self, event):
        """Garante que a conexão seja fechada ao fechar a janela."""
        if self.communicator:
            self.communicator.disconnect()
        event.accept()
